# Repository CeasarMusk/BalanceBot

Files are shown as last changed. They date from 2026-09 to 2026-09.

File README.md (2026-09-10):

# Inverted Pendulum Balance Bot
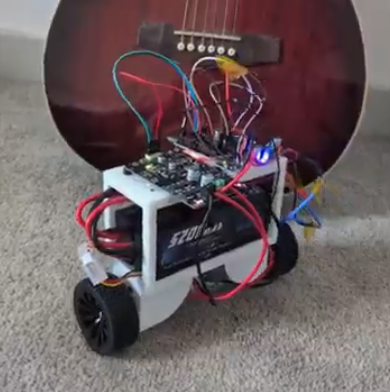
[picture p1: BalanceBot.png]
BalnceBot
 

## A self balancing bipedal wheeled bot 
Over my summer term, i wanted to learn how to actually build something. This doohickey is the product of 2 months of learning and trial and error

POST Build:
This project was my entryway to Engineering. I just wanted to quickly make a list of all of the topics I've learned over the course of ~2 months 
  - 3D modeling
  - 3D printing
  - PID
  - Control Theory 
  - Mechatronics 
  - Fighting the urge to slam the bot into the wall
  - Electrical Engineering

## What I Would Do Differently
If I built this again, I would start with:

- Motors with faster acceleration
- Encoders on both motors
- A motor driver selected before the mechanical design
- A more deliberate power distribution design
- A better-defined control architecture before tuning

## Biggest Hurdles
- PID
    - Seriosuly tuning PD was miserable
    - So much jitter
- Motor
    - Did not understand what stall current was at the start of the project. Immediately fried my first Motor Driver
    - Lack of Encoders
        - Was not able to determine how much my motors were actually turning. My Left motor needed 1.4v to start, while the right only needed 0.8v. They both spun at different speeds!!!
- Solder
    - Did NOT know about jump cables at first, so i was hand soldering EVERY DAMN WIRE

## Tools Used:
- FreeCad
- Arduino-Cli
- Orca-Slicer with PETG

## Resources Utilized
- [edX Mechatronics Course](https://www.edx.org/learn/engineering/the-georgia-institute-of-technology-the-mechatronics-revolution-fundamentals-and-core-concepts)
- [The Organic Chemist](https://www.youtube.com/@TheOrganicChemistryTutor)
- [Getting Started in Electronics](https://www.amazon.com/dp/0945053282)
###### P.S. The book is singlehandedly the most important part here

## Construction Materials
| Part | Price |
|--- | --- |
| [ESP32](https://www.amazon.com/dp/B08D5ZD528) | $17 x1 |
| [MDD10A Driver](https://www.amazon.com/dp/B07CW34YRB) | $23 x1 |
| [12V 300RPM Motor](https://www.amazon.com/dp/B072N84V8) | $15 x2 |
| [MPU6050](https://www.amazon.com/dp/B00LP25V1A?th=1) | $12 x1 |
| [S2](https://www.amazon.com/dp/B076Z778MJ) | $39 x2 |
| [Buck Converters](https://www.amazon.com/dp/B0DBVYP91F?th=1)| $8 x2 |
| [Heat Inserts] | N/A |

## General Overview
    1. Calibrate Gyro/Accel
    2. Pass MPU output to a Complimentary Filter
    3. Send output to a PD controller
    4. PD will convert error to PMW Signal for the motors
    5. Pray?

## Pinout

| Component | ESP32 Pin |
|---|---:|
| MPU6050 SDA | GPIO 21 |
| MPU6050 SCL | GPIO 22 |
| Motor A PWM | GPIO 25 |
| Motor A Direction | GPIO 33 |
| Motor B PWM | GPIO 32 |
| Motor B Direction | GPIO 26 |
| Status LED | GPIO 2 |

## If recreating this project:
Please remember to disable WIFI when actually tuning PD. If not, you start hammering your network
I have included the STL Files, print them o.2mm layers with 10ish slow layers to start with. This helps to make sure each screw hole isnt stringy

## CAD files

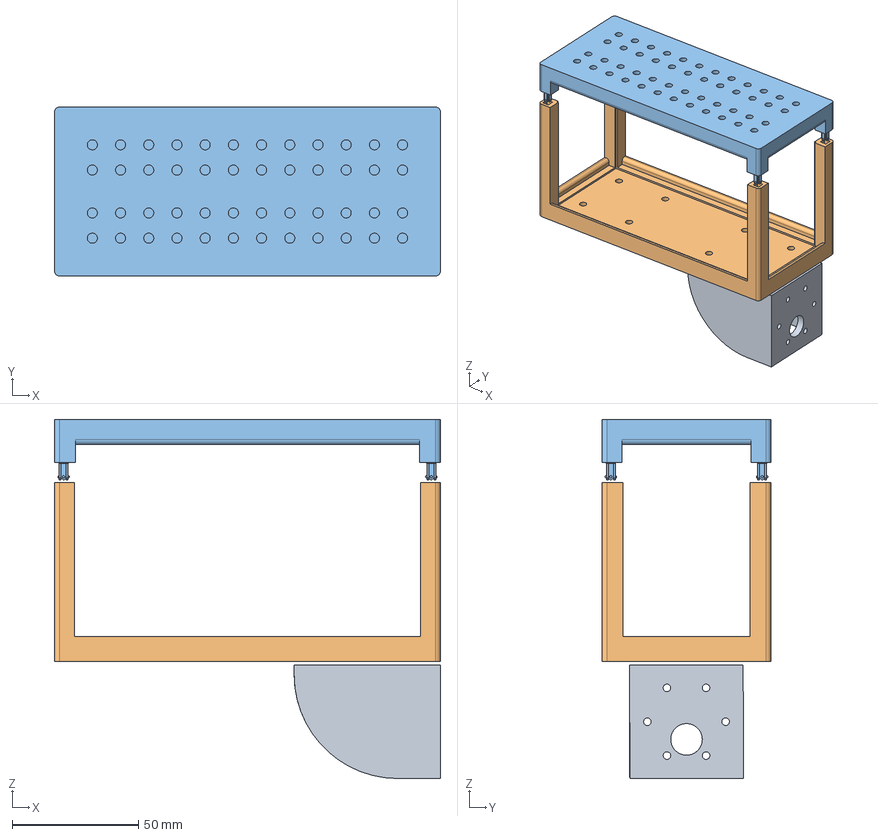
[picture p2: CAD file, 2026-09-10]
stl/BalanceBot.FCStd
153.0 x 67.0 x 142.3 mm
Motor_Mount001
Base_Plate
Top_Plate001

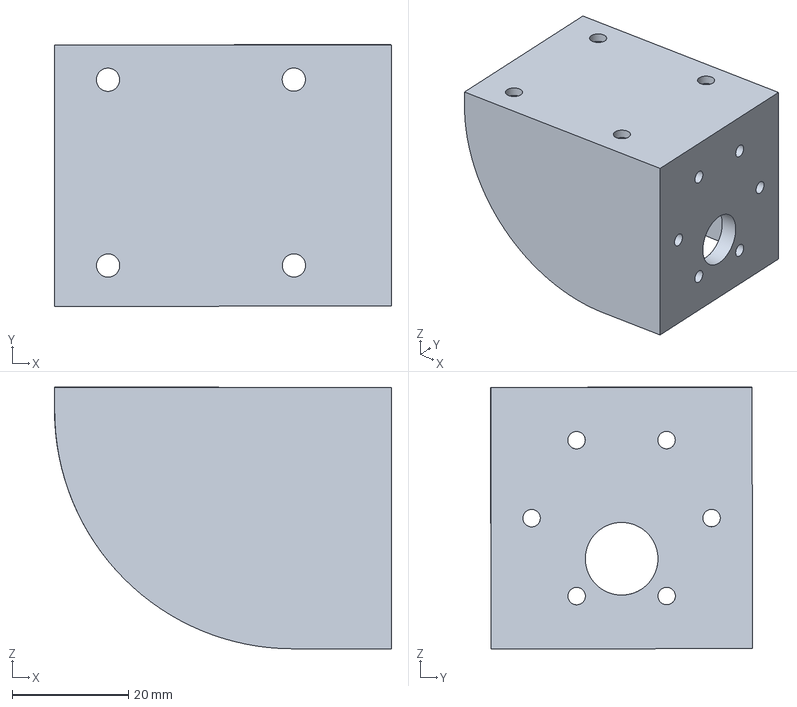
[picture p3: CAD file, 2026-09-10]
stl/BalanceBot-Motor_Mount001.3mf
58.0 x 45.1 x 45.1 mm

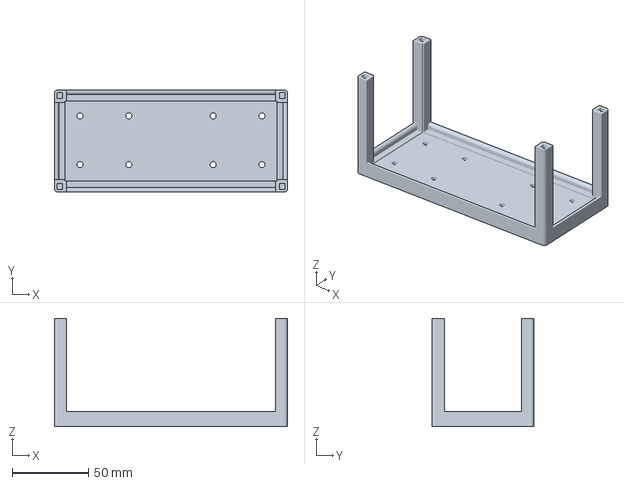
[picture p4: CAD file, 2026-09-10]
stl/BalanceBot-Base_Plate.3mf
153.0 x 67.0 x 71.0 mm

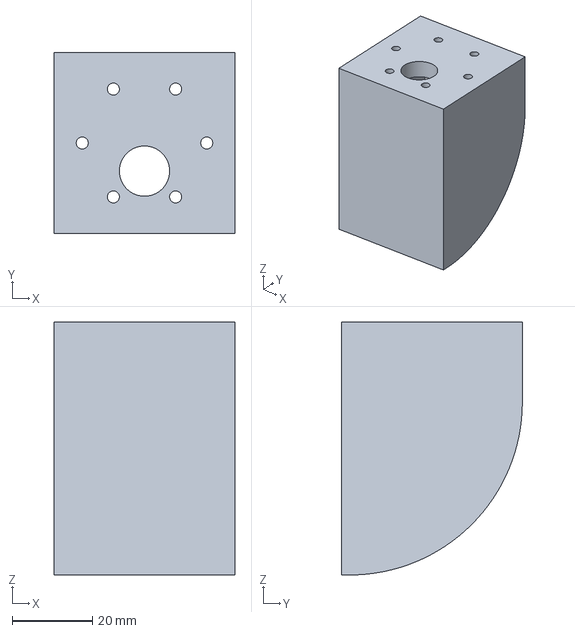
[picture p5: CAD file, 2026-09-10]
stl/BalanceBot-Body.3mf
45.0 x 45.0 x 63.0 mm

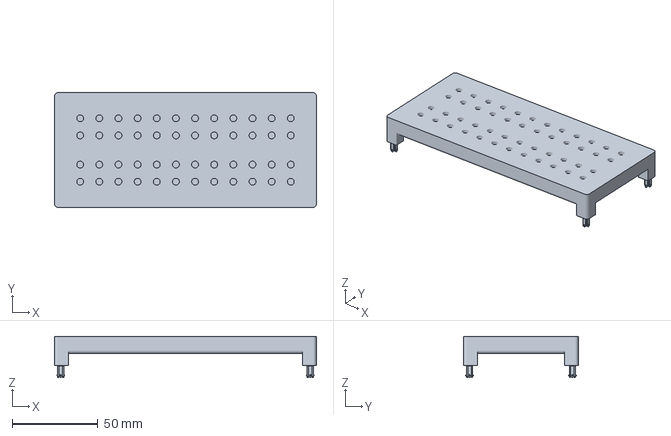
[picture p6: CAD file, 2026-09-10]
stl/BalanceBot-Top_Plate001.3mf
153.0 x 67.0 x 24.0 mm

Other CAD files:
stl/BalanceBot.3mf

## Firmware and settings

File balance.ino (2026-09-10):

#include <Wire.h>
#include <Adafruit_MPU6050.h>
#include <Adafruit_Sensor.h>
#include <ElegantOTA.h>
#include <WiFi.h>
#include <AsyncTCP.h>
#include <ESPAsyncWebServer.h>
#include <WebSerial.h>

//Please remember to change the Macros in this file
#include <secrets.h>
//Holy fuck turn the wifi off when setting to 250Hz i stg it burned my first esp32 


//trying to not end it all

#define LOG_PRINTf(x)   \
    do {               \
        Serial.printf(x);    \
        WebSerial.printf(x); \
    } while (0)
#define LOG_PRINTLN(x) \
    do {               \
        Serial.println(x);    \
        WebSerial.println(x); \
    } while (0)
// ╔══════════════════════════════════════════════════════════╗
// ║                  Init Pins                               ║
// ╚══════════════════════════════════════════════════════════╝
#define SCL 22
#define SDA 21

// ╔══════════════════════════════════════════════════════════╗
// ║                  Motor Shit                              ║
// ╚══════════════════════════════════════════════════════════╝

#define FREQ 20000
#define PWMCHANNEL0 0
#define PWMCHANNEL1 1
#define RESOLUTION 8 
#define DUTYCYCLE 220

#define DIR1 33
#define DIR2 26
#define PMW1 25
#define PMW2 32


Adafruit_MPU6050 mpu;
AsyncWebServer server(80);

unsigned long prevTime= 0;

void setup(void) {
// ╔══════════════════════════════════════════════════════════╗
// ║                  Init Pins                               ║
// ╚══════════════════════════════════════════════════════════╝
  pinMode(DIR1,OUTPUT);
  pinMode(DIR2,OUTPUT);
  pinMode(PMW1,OUTPUT);
  pinMode(PMW2,OUTPUT);
  pinMode(2,OUTPUT);
  
  // Set these to low, I totally fried my first board because the pins were floating HIGH at startup
  digitalWrite(DIR1,LOW);
  digitalWrite(DIR2,LOW);
  digitalWrite(PMW1,LOW);
  digitalWrite(PMW2,LOW);


  Serial.begin(115200);
  while (!Serial)
    delay(10); // will pause Zero, Leonardo, etc until serial console opens
  LOG_PRINTf("ESP32 Booting up\n");
  delay(5000); // This is needed during Programming phase, the serial connection will output tons of garbage without it

// ╔══════════════════════════════════════════════════════════╗
// ║                  OTA Maybe?                              ║
// ╚══════════════════════════════════════════════════════════╝
  //WiFi.mode(WIFI_STA);
  //WiFi.begin(SSID,WIFI_PASSWORD);
  //LOG_PRINTf("Testing WiFi\n");

  //while(WiFi.status() != WL_CONNECTED){
  //  delay(500);
   // LOG_PRINTf(".");
  //}

  Serial.printf("\nConnected to %s\n IP Address: %s\n", SSID,WiFi.localIP().toString().c_str());
  //WebSerial.printf("\nConnected to %s\n IP Address: %s\n", SSID,WiFi.localIP().toString().c_str());
  //server.on("/", HTTP_GET, [](AsyncWebServerRequest *request) {
  //  request->send(200, "text/plain", "Hi! I am ESP32.");
  //});

  //server.begin();
  LOG_PRINTLN("HTTP server started");

  //ElegantOTA.begin(&server);    // Start ElegantOTA
  //WebSerial.begin(&server);
  

// ╔══════════════════════════════════════════════════════════╗
// ║                  MPU Init                                ║
// ╚══════════════════════════════════════════════════════════╝
  if (!mpu.begin()) {
    Serial.println("Failed to find MPU6050 chip");
    while (1) {
      delay(10);
    }
  }
  Serial.println("MPU Found");
  mpu.setAccelerometerRange(MPU6050_RANGE_8_G);
  mpu.setGyroRange(MPU6050_RANGE_500_DEG);
  mpu.setFilterBandwidth(MPU6050_BAND_44_HZ);
  calibrateGyro();
  calibrateAccelAngle();

  ledcAttachChannel(PMW1,FREQ,RESOLUTION,PWMCHANNEL0);
  ledcAttachChannel(PMW2,FREQ,RESOLUTION,PWMCHANNEL1);
  digitalWrite(2, HIGH);
  delay(500);
  digitalWrite(2, LOW);
  delay(500);
  prevTime=micros();
}

float angle = 0.00f;
int elapsedTime;
float gyroCalibrated  = 0.0f;
float accelCalibrated = 0.0f;
float targetAngle     = 0.0f; // This needs to be played with to find where the bot actually balances
float error           = 0.0f;
float Kp              = 19.0f;
float Ki              = 0.0f;
float Kd              = 0.05f;
float motorBCorrection= 1.05f;
float motorBOffset    = 5.0f;

float output          = 0.0f;

void calibrateGyro(){
  sensors_event_t a,g,temp;
  
  int samples = 500;
  for(int i = 0; i < samples;i++){
    mpu.getEvent(&a,&g,&temp);
    gyroCalibrated+=g.gyro.x;
    delay(2);
  }

  gyroCalibrated=gyroCalibrated/samples;
}

void calibrateAccelAngle() {
    sensors_event_t a, g, temp;

    accelCalibrated = 0.0f;

    int samples = 500;

    for (int i = 0; i < samples; i++) {
        mpu.getEvent(&a, &g, &temp);

        float accelAngle =
            atan2(a.acceleration.y, a.acceleration.z) * 180.0f / PI;

        accelCalibrated += accelAngle;

        delay(2);
    }

    accelCalibrated /= samples;
}



void loop() {
  
  //ElegantOTA.loop();
  
  //Serial.print("\033[2J\033[H");
  // General Comp Filter, will organize code later
  
  
  unsigned long curTime=micros();

  if(curTime - prevTime >= 4000){ //250Hz
    sensors_event_t a, g, temp;

    mpu.getEvent(&a, &g, &temp);

    float dt = (curTime - prevTime)/1000000.0f;
    prevTime = curTime;

  
    float gyroRate= (g.gyro.x - gyroCalibrated) * 180.0f/PI;
    float accelAngle = (atan2(a.acceleration.y,a.acceleration.z) * (180.0f/PI)) - accelCalibrated;

    //Actual Filter
    
    angle = 0.98f * (angle+(gyroRate*dt)) +  0.02f * accelAngle;
    error=targetAngle-angle;
    
    // Emergency Stop
    if(angle > 50 || angle < -50){
      esp_deep_sleep_start();
    }

    output=(Kp*error)+(Kd*-(gyroRate));
    
    output = constrain(output, -255.0f, 255.0f);
    Serial.printf("Gyro angle over dt: %f\nAccelAngle Current: %f\nFiltered angle: %f\nError: %f\nOutput: %f \n\f", gyroRate, accelAngle, angle, error, output);
    
    

    if( output >=0 ){
      digitalWrite(DIR1,LOW);
      digitalWrite(DIR2,LOW);
    } else {
      digitalWrite(DIR1,HIGH);
      digitalWrite(DIR2,HIGH);
    } 
    int dutyCyle=abs((int)output);
    ledcWrite(PMW1, constrain((dutyCyle*motorBCorrection),0,255.0f)+motorBOffset);
    ledcWrite(PMW2, dutyCyle);
    
  }

  

  /* LOGIC TABLE
   *
   *  PWM | DIR | OUTPUT
   *   0  |  0  |   X
   *   0  |  1  |   X
   *   1  |  0  |   B
   *   1  |  1  |   F
   * 
   * */ 

  


  //First time programming esp32!! Not deleting this, its baller 
//  digitalWrite(LED_BUILTIN,HIGH);
//  delay(250);
//  digitalWrite(LED_BUILTIN,LOW);
//  delay(250);
}

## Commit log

2026-08-03 Added i2c detection for IMU. Prints a LOT of garbage during setup??
2026-08-04 Added a bunch of bullshit (starting motor stuff)
2026-08-05 Added OTA, fucking outdated libs caused issues
    [balance.ino]
2026-08-05 WebSerial works, i fried my fucking motor driver though
    [partitions.csv]
2026-08-24 Changed Motor Driver, test WORKS FUCK YEA
2026-08-28 Complimentary Filter added for IMU
2026-08-29 Added calibration for MPU Gyro/Accel. Works much better
2026-08-29 P(!I)D added, need to link to motor schema next
2026-09-09 Tuned, for the most part. i cant be bothered to fix it anymore
    [balance.ino]
2026-09-09 Stopped tracking build
    [partitions.csv]
2026-09-10 Added 3mf/stl's
    [BalanceBot-Base_Plate.3mf, BalanceBot-Body.3mf, BalanceBot-Motor_Mount001.3mf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]
